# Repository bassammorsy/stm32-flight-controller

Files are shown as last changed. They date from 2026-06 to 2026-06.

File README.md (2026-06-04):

# STM32F405 Quadcopter Flight Controller
A custom 4-layer flight controller PCB designed from scratch in KiCad, targeting Betaflight compatibility with 4S–6S LiPo input. Designed, laid out, and submitted for SMT assembly through JLCPCB.

## Specifications
| Parameter | Detail |
|---|---|
| Microcontroller | STM32F405RGTx — ARM Cortex-M4 @ 168 MHz |
| Input Voltage | 4S–6S LiPo (14.8V–25.2V) |
| Power Architecture | TPS54360DDA Buck (5V/3.5A) → SPX3819 LDO (3.3V) |
| IMU | ICM-42688-P (SPI1, 6-DOF, 32kHz ODR) |
| Barometer | BMP388 (SPI3) |
| Magnetometer | QMC5883L (I2C2) |
| GPS | SAM-M10Q-00B (UART3, integrated antenna) |
| OSD | AT7456E with 27MHz crystal |
| USB | USB-C with USBLC6-2SC6 ESD protection |
| PCB | 4-Layer, 74×108mm, FR4 TG135, LeadFree HASL |
| Motor Outputs | 4× DShot (TIM1 CH1-3, TIM8 CH4) |
| Assembly | JLCPCB SMT — 43 component BOM |

## PCB Layout
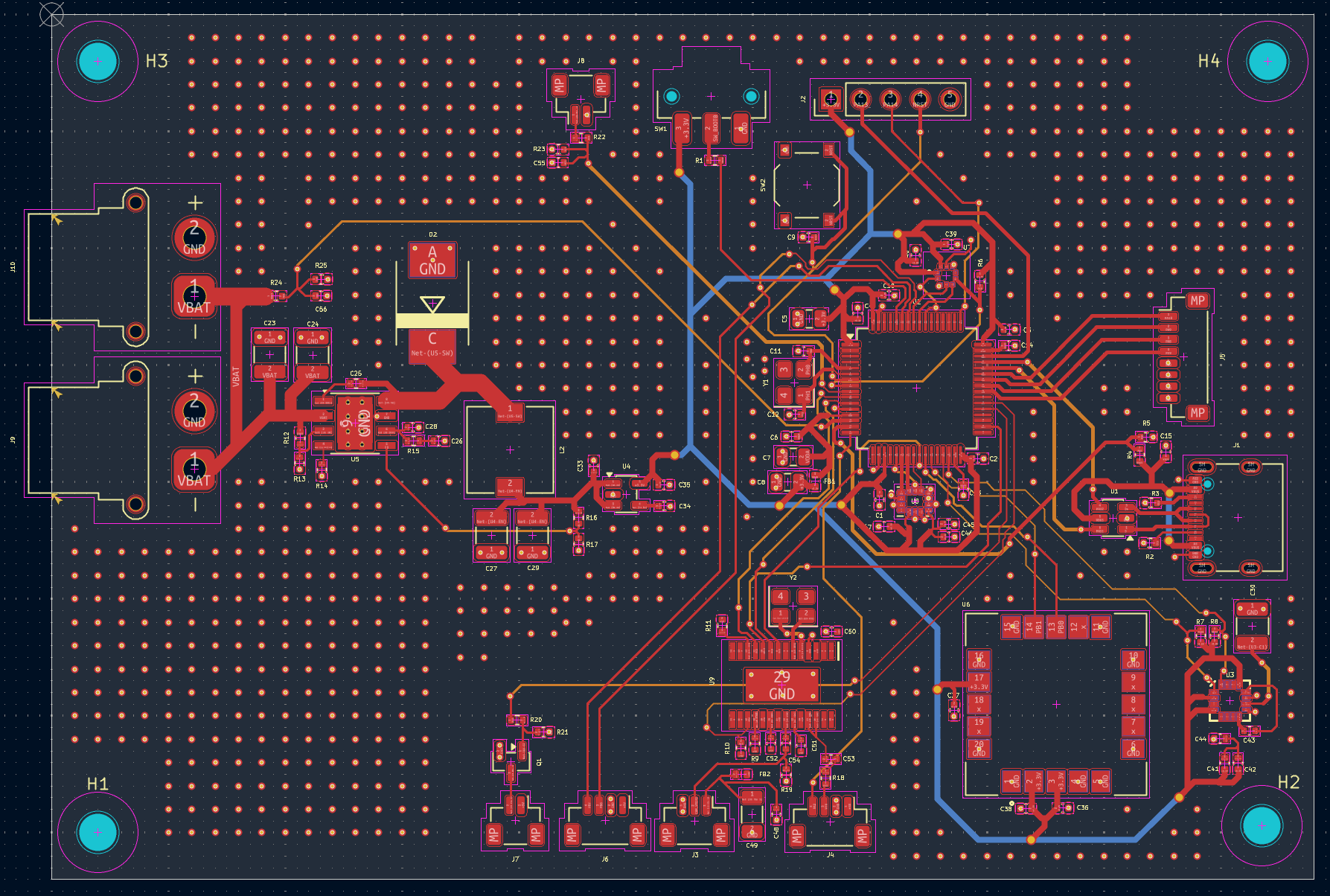
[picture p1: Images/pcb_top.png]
PCB Top View


## Design Portfolio
A full design portfolio documenting every schematic section, PCB layout decision, component selection rationale, and datasheet calculations is available below.

[📄 View Full Design Portfolio (PDF)](Docs/STM32_Drone_FC_Portfolio.pdf)

## Key Design Decisions
- 4-layer stackup: F.Cu (signals) / In1.Cu (GND plane) / In2.Cu (signal overflow) / B.Cu (3.3V distribution)
- Switched node area minimized around TPS54360 to reduce EMI
- Decoupling capacitors placed within 1–2mm of every power pin
- Ground via stitching at all signal layer transitions
- Magnetometer placed at maximum distance from power section
- USBLC6-2SC6 placed immediately at USB-C connector before any D+/D− routing

## Repository Structure

    Hardware/
        Schematic/     — KiCad schematic files
        PCB/           — KiCad PCB layout files
        Gerbers/       — Fabrication files for JLCPCB
    BOM/               — Bill of materials with LCSC part numbers
    Docs/              — Full design portfolio PDF

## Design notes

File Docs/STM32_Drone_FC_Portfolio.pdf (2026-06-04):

Custom STM32F405 Quadcopter Flight Controller — Design Portfolio

# STM32F405 QUADCOPTER FLIGHT CONTROLLER

## PCB Design Portfolio

Bassam Morsy | University of Washington
4-Layer KiCad Design | JLCPCB Fabrication | Betaflight Compatible
Microcontroller | STM32F405RGTx — ARM Cortex-M4 @ 168 MHz
Input Voltage | 4S–6S LiPo (14.8V–25.2V)
Power Architecture | TPS54360DDA Buck → 5V | SPX3819 LDO → 3.3V
IMU | ICM-42688-P (SPI1, 6-DOF, 32kHz ODR)
Sensors | BMP388 Baro | QMC5883L Mag | SAM-M10Q GPS
OSD | AT7456E with 27 MHz crystal
PCB | 4-Layer, 74×108 mm, HASL, FR4 TG135
Motor Outputs | 4× DShot (TIM1 CH1-3, TIM8 CH4)

STM32F405 Quadcopter FC — Design Portfolio | Page 2

Table of Contents 1 Project Overview 2 System Architecture 3 Power Architecture

### 3.1 TPS54360DDA Buck Converter 3.2 SPX3819M5-L-3-3 LDO Regulator 3.3 VDDA Analog Power Filter

### 4 STM32F405 Microcontroller

### 4.1 Power Decoupling Network 4.2 Crystal Oscillator (8 MHz) 4.3 BOOT0 Configuration 4.4 NRST Reset Circuit 4.5 SWD Debug Interface

5 USB-C Interface 6 Inertial Measurement Unit — ICM-42688-P 7 Barometer — BMP388 8 OSD — AT7456E 9 Magnetometer — QMC5883L

### 10 GPS — SAM-M10Q-00B 11 FPV Camera Input 12 Buzzer Driver 13 Connectors & Peripheral I/O 14 PCB Layout

14.1 Stackup & Layer Strategy 14.2 Overall Placement Strategy 14.3 Power Section Layout 14.4 STM32 Area Layout 14.5 IMU Layout 14.6 OSD & 5V Area Layout 14.7 Barometer Layout 14.8 Magnetometer Layout 14.9 GPS Module Layout 14.10 USB-C Layout 14.11 Crystal & VDDA Layout 14.12 Trace Widths & Impedance 14.13 Ground Plane Strategy

### 15 Manufacturing & BOM

# 1. Project Overview

This portfolio documents the complete design of a custom quadcopter flight controller built from scratch using KiCad EDA. The board targets Betaflight firmware compatibility and is designed for 4S–6S LiPo battery systems (14.8V–25.2V nominal). Every component value, footprint, and routing decision was made with explicit engineering justification grounded in datasheets, signal integrity principles, and power electronics theory. The board was fabricated by JLCPCB as a 4-layer PCB and partially assembled via their SMT service, with through-hole and large SMD connectors hand-soldered.

The design goal was to produce a professional-grade flight controller equivalent to commercial offerings such as the Matek F405 or Holybro Kakute F4, while applying first-principles engineering at every stage. This includes full datasheet-driven component selection, calculated feedback networks, analog power isolation, differential pair routing, and a deliberate 4-layer stackup strategy to minimize EMI and maximize signal integrity.

# 2. System Architecture

The flight controller is organized around three functional domains: power conversion, the main processing core, and the sensor/peripheral subsystem. Battery voltage enters through two XT30 connectors (J9 for ESC power pass-through, J10 for FC input), is stepped down by a synchronous buck converter to 5V, then regulated further by an LDO to 3.3V for digital logic and sensors. The analog supply (VDDA) for the STM32's ADC is further filtered from the 3.3V digital rail using a ferrite bead and capacitor network.

Block | Component | Interface | Rail
Main MCU | STM32F405RGTx | — | 3.3V
Buck Converter | TPS54360DDA | — | VBAT → 5V
LDO | SPX3819M5-L-3-3 | — | 5V → 3.3V
IMU | ICM-42688-P | SPI1 (PA5/6/7, CS:PC4) | 3.3V
Barometer | BMP388 | SPI3 (PB3/4/5, CS:PC0) | 3.3V
Magnetometer | QMC5883L | I2C2 (PB10/11) | 3.3V
GPS | SAM-M10Q-00B | UART3 (PB0/1) | 3.3V
OSD | AT7456E | SPI2 (PC3/PB13/PC2, CS:PC5) | 5V
ESD Protection | USBLC6-2SC6 | USB D+/D− | —
Motor Outputs | 4× JST-SH | TIM1 CH1-3, TIM8 CH4 | 5V
Receiver | JST-SH 4-pin (J5) | UART1 (PA9/10) | 5V
VTX | JST-SH 4-pin (J4) | UART2 (PA2) | 5V

# 3. Power Architecture

The power system must handle a wide input range (4S LiPo: 14.8V nominal, 16.8V full charge; 6S: 22.2V nominal, 25.2V full charge) and deliver clean, stable power to a mixed analog-digital load. A two-stage approach was chosen: a high-efficiency switching buck converter to handle the large voltage step-down, followed by a low-noise LDO for the final digital rail, with additional LC filtering for the sensitive analog domain.

## 3.1 TPS54360DDA Buck Converter — VBAT → 5V @ 3.5A

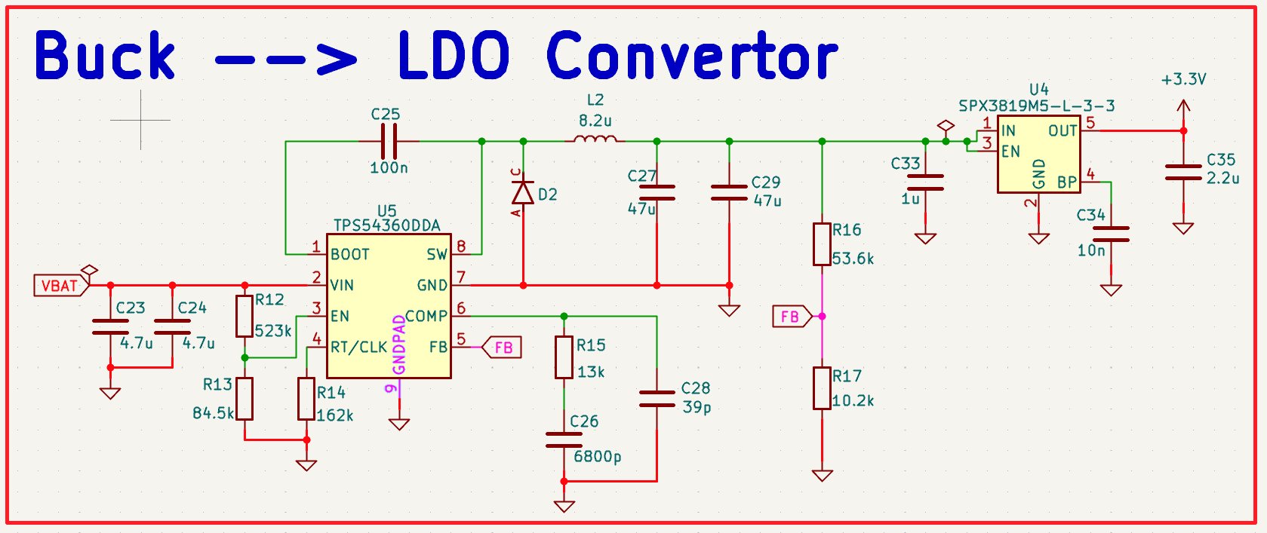
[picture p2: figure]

Figure 1: Complete power section schematic — TPS54360DDA buck converter and SPX3819 LDO

The Texas Instruments TPS54360DDA was selected for its wide input voltage range (4.5V–60V), 3.5A continuous output capability, internal high-side MOSFET, and availability through JLCPCB assembly. The switching frequency was set to 600 kHz by the RT resistor R14 (162 kΩ), calculated directly from the TPS54360 datasheet equation: R_T = (1/f_sw − 100ns) / (10.05 × 10■¹²). Higher switching frequency allows a smaller inductor at the cost of slightly higher switching losses — 600 kHz is the recommended sweet spot for this IC balancing efficiency and component size.

Output Voltage Feedback Network (R15, R16, R17):
R15 (upper, FB to VOUT) = 13 kΩ
R16 (lower, FB to GND) — sets output voltage via voltage divider
Target output: 5.0V. Equation: V_OUT = V_REF × (1 + R_upper/R_lower), V_REF = 0.8V Calculated: R16 = 10.2 kΩ, R17 = 53.6 kΩ — verified against datasheet
UVLO (Undervoltage Lockout) — R12, R13:
R12 = 523 kΩ (upper), R13 = 84.5 kΩ (lower)
Sets UVLO start threshold ~14.5V and stop ~13V, preventing operation below 4S minimum Protects battery from deep discharge and ensures stable startup
Compensation Network — R15, C26, C28:
R15 = 13 kΩ, C26 = 6800 pF, C28 = 39 pF
Type II compensation network stabilizes the control loop across all load conditions
C26 sets the zero frequency, C28 adds a high-frequency pole to attenuate switching noise

Values calculated per TPS54360 datasheet Section 9.2 compensation procedure Inductor — L2 (8.2 µH):
L = (V_IN − V_OUT) / (f_sw × ∆I_L) — calculated for 30% peak-to-peak current ripple At V_IN=25.2V, V_OUT=5V, f_sw=600kHz, I_OUT=3A: L ≈ 8.2 µH
RS0630-8R2MS selected: 7.3×7.3mm power inductor, I_sat > 4A, low DCR
Catch Diode — D2 (B560C-13-F):
Schottky diode, 60V/5A rated, DO-214AB (SMA-C) package
Placed as close as possible to the SW pin — this is the critical hot node
Low forward voltage (0.52V typ) minimizes conduction losses during freewheeling phase Input Capacitors — C23, C24 (4.7 µF × 2, 1210):
Placed immediately at VBAT/VIN pins to decouple high-frequency switching transients 1210 package chosen for high voltage rating (≥50V) and low ESR at switching frequency Two caps in parallel halves effective ESL and ESR
Output Capacitors — C27, C29 (47 µF × 2, 1210):
Large bulk capacitance on output to minimize ripple and support load transients
Placed at output node, away from IC side, to complete the output current loop locally Bootstrap Cap — C25 (100 nF):
Connected between BOOT and SW pins per datasheet
Provides gate drive voltage for the internal high-side MOSFET
Must be placed as close to BOOT pin as possible

## 3.2 SPX3819M5-L-3-3 LDO — 5V → 3.3V

The MaxLinear SPX3819M5-L-3-3 LDO was chosen for its low dropout voltage (340 mV at 500 mA), low quiescent current (90 µA), and built-in enable pin and thermal/overcurrent protection. It takes the clean 5V buck output and produces 3.3V for the STM32 and all digital sensors. The total 3.3V load was calculated from datasheets: STM32F405 (~50 mA active), ICM-42688-P (3.1 mA), BMP388 (0.7 mA), QMC5883L (2.5 mA), SAM-M10Q (15 mA typ), plus decoupling overhead, totaling approximately 99 mA — well within the 500 mA rating.

Input cap C33 = 1 µF (stability, placed at IN pin)
Output caps C34 (10 nF) + C35 (2.2 µF) — output filter, improves PSRR and transient response
EN pin connected via R16/R17 voltage divider from buck output — enables LDO only when 5V is stable BP pin bypassed with 10 nF (C34) per datasheet requirement

## 3.3 VDDA Analog Power Filter

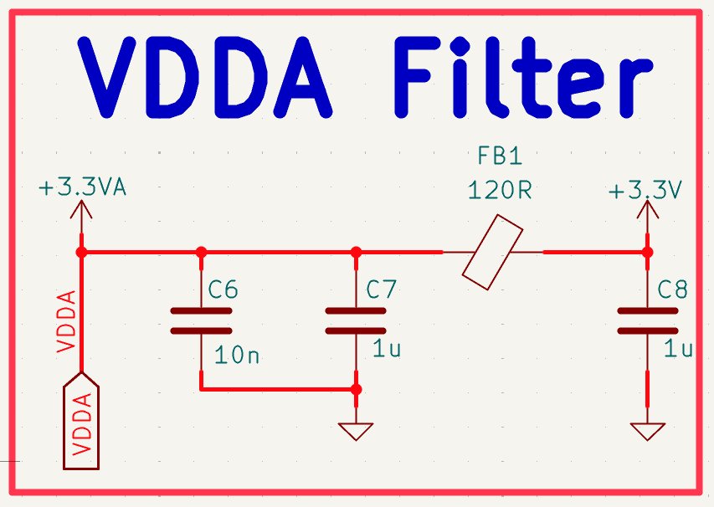
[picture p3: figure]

Figure 2: VDDA analog supply filter — FB1 ferrite bead with C6/C7/C8 capacitor network

The STM32F405 has a dedicated VDDA pin for its ADC, DAC, and analog comparator circuitry. Feeding VDDA directly from the digital 3.3V rail would couple switching noise and digital ground bounce directly into the ADC reference, degrading measurement accuracy. A ferrite bead filter was therefore implemented between the digital 3.3V rail and VDDA.

FB1 — 120 Ω @ 100 MHz, 0402:
Sunlord GZ1005D121TF ferrite bead acts as a low-pass filter at high frequencies
Passes DC and low-frequency signals (negligible DC resistance) but attenuates switching noise above ~10 MHz 120 Ω impedance at 100 MHz chosen per STM32F4 reference manual recommendation
Filter Capacitors:
C6 = 10 nF (0402): high-frequency bypass, targets self-resonance near 100 MHz
C7 = 1 µF (0805): mid-frequency bulk decoupling, handles lower-frequency noise
C8 = 1 µF (0805): post-ferrite output stabilization on VDDA side
The combination creates a cascaded LC filter providing >40 dB attenuation of switching noise above 10 MHz

# 4. STM32F405 Microcontroller

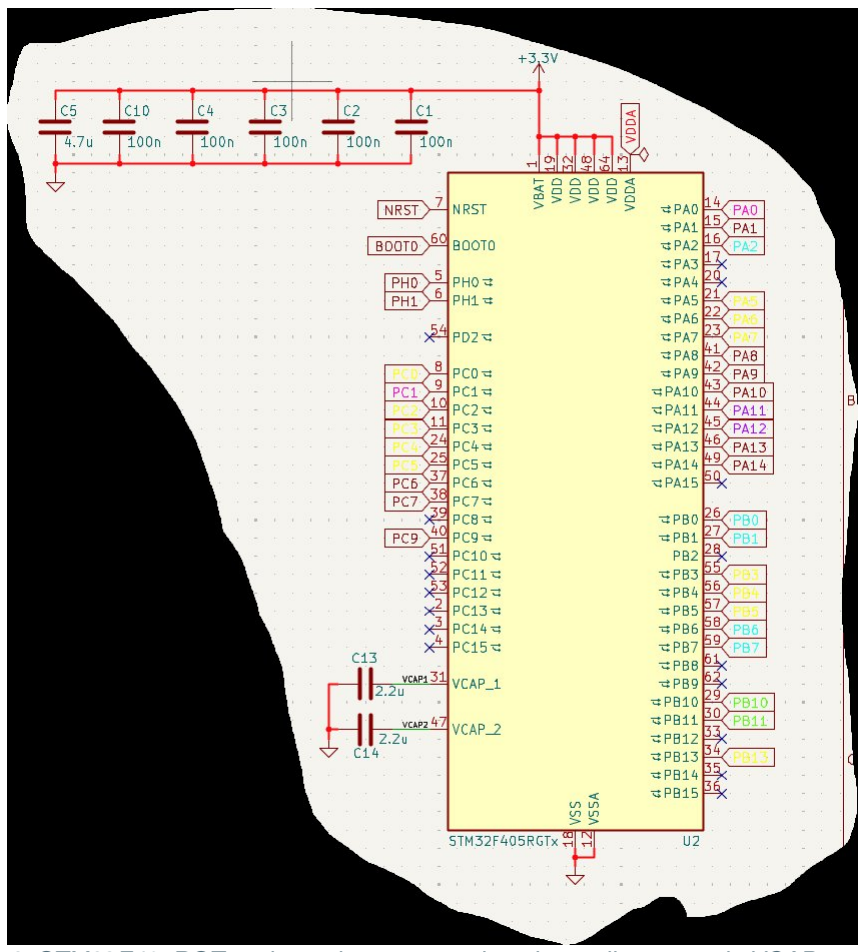
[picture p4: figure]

Figure 3: STM32F405RGTx schematic — power pins, decoupling network, VCAP capacitors

The STM32F405RGTx is an ARM Cortex-M4F microcontroller running at up to 168 MHz with an FPU. It was chosen over the STM32F411 specifically to gain additional UART peripherals, CAN bus support, and full alignment with existing Betaflight hardware targets. The LQFP-64 package was used for its 0.5 mm pitch solderable leads, allowing JLCPCB SMT assembly.

## 4.1 Power Decoupling Network

Per the STM32F405 datasheet Figure 17, each VDD pin must have its own 100 nF decoupling capacitor placed as close as possible to the pin. The STM32F405 has four VDD pins (pins 19, 48, 63, 64) and one VDDA pin. The decoupling strategy follows three principles:

C1–C4 = 100 nF 0402 (X7R) — one per VDD pin, placed within 1–2 mm of each pin
C5 = 4.7 µF 0805 — bulk bypass for the combined VDD network, handles low-frequency transients
VDDA supplied through FB1 ferrite filter (see Section 3.3)
The 100 nF capacitors are sized to have their self-resonant frequency near the switching frequencies of concern (~100 MHz for digital noise). At resonance, impedance is minimized to ESR only (~10 mΩ), providing the lowest possible impedance path for transient return current. Using 0402 packages minimizes parasitic inductance compared to larger packages, keeping self-resonant frequency high. The 4.7 µF bulk cap provides charge reservoir for larger, slower transients such as peripherals switching on.

VCAP Pins (C13, C14 = 2.2 µF each):
VCAP1 (pin 31) and VCAP2 (pin 47) connect to the internal voltage regulator output
The STM32F405 has an internal 1.2V core voltage regulator requiring external capacitors on VCAP for stability 2.2 µF specified by STM32F405 datasheet — must not be omitted or the core regulator will oscillate Connected to GND, not 3.3V — these are regulator output caps, not bypass caps

## 4.2 Crystal Oscillator — 8 MHz

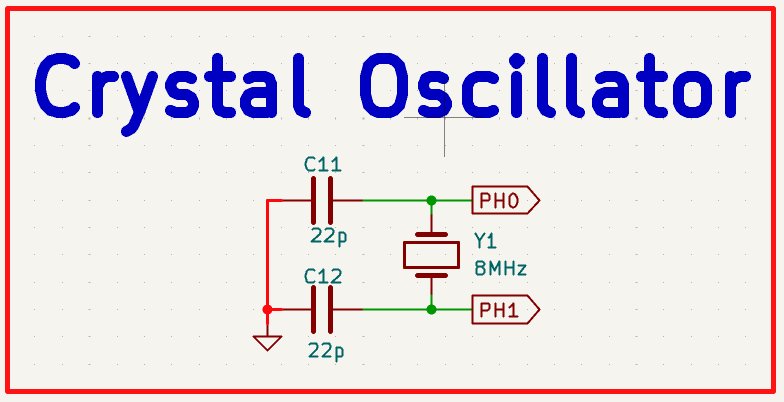
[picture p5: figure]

Figure 4: 8 MHz crystal oscillator circuit — Y1 with 22 pF load capacitors C11/C12

The STM32F405 uses a 4–26 MHz external crystal on the HSE (High Speed External) oscillator input at pins PH0 and PH1. An 8 MHz crystal was chosen because Betaflight targets the STM32F405 with an 8 MHz HSE, and the PLL is configured to multiply this to 168 MHz system clock. The crystal frequency must match the Betaflight firmware target configuration.

Load Capacitors — C11, C12 = 22 pF (C0G/NP0, 0402):
Crystal oscillator circuits require load capacitors on each pin to ground
Load capacitance C_L = (C11 × C12)/(C11 + C12) + C_stray ≈ 11 pF + C_stray
Typical stray capacitance ~3–5 pF, giving effective C_L ≈ 14–16 pF
C0G/NP0 dielectric chosen for temperature stability — critical for clock accuracy
Traces from crystal pins to STM32 kept as short as possible (<5 mm) to minimize stray capacitance
Traces surrounded by ground copper to shield from noise coupling
The 27 MHz crystal Y2 used for the AT7456E OSD follows the same design approach, as the OSD chip requires a separate clock independent of the MCU.

## 4.3 BOOT0 Configuration

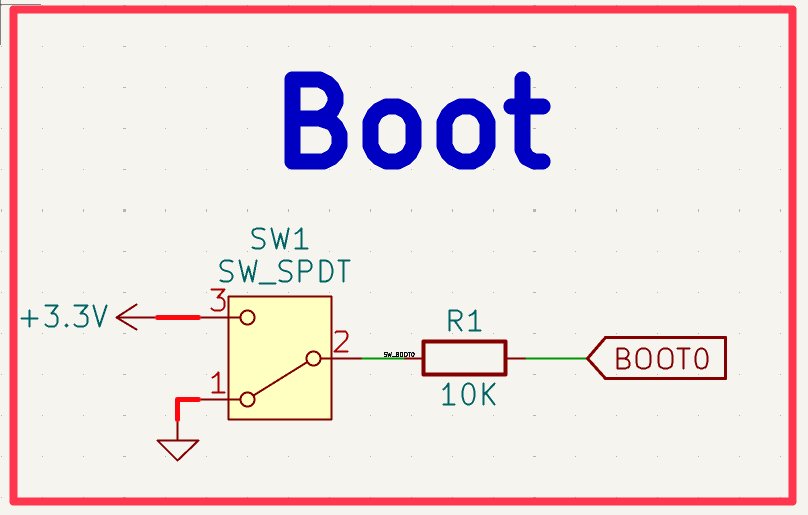
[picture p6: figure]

Figure 5: BOOT0 circuit — SPDT slide switch SW1 with 10 kΩ pull-down R1

The BOOT0 pin determines the boot mode of the STM32 on reset. When BOOT0 is low (GND), the STM32 boots from user flash — normal operation for Betaflight. When BOOT0 is pulled high (3.3V), the STM32 enters the internal bootloader, enabling USB DFU firmware flashing without a separate programmer.

SW1 = C&K; JS102011SAQN SPDT slide switch — selects between GND and 3.3V
R1 = 10 kΩ pull-down — ensures BOOT0 defaults to GND when switch is in run position
10 kΩ chosen to limit current while providing a strong enough logic low against noise
This eliminates the need for an ST-LINK for routine firmware updates — the user simply slides SW1, plugs in USB, and flashes via DFU, then slides back for normal operation.

## 4.4 NRST Reset Circuit

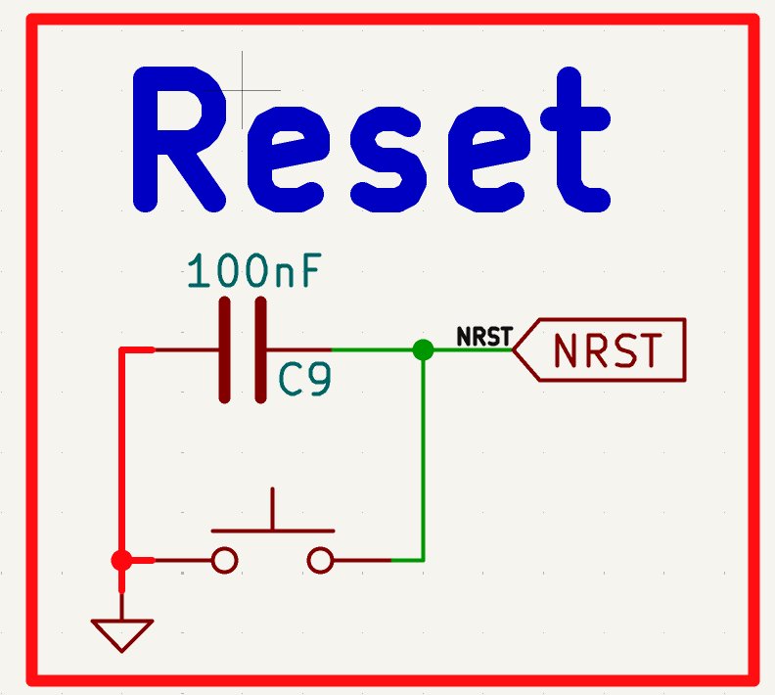
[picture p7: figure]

Figure 6: NRST reset circuit — momentary push button with 100 nF filter capacitor C9

The NRST pin is an active-low reset. A momentary push button (SW2) pulls NRST to GND when pressed, resetting the MCU. C9 (100 nF) is placed between NRST and GND as specified in the STM32 reference manual to filter out noise and ESD spikes on the reset line, preventing spurious resets in the electrically noisy drone environment.

STM32 internal pull-up keeps NRST high during normal operation
C9 = 100 nF creates an RC filter — time constant with internal ~40 kΩ pull-up is ~4 ms
This debounces the mechanical switch and filters conducted EMI from ESCs

## 4.5 SWD Debug Interface

Figure 7: 5-pin SWD debug header J2 — SWDIO/PA13, SWCLK/PA14, NRST, 3.3V, GND

A 5-pin 2.54mm pitch through-hole header provides Serial Wire Debug (SWD) access. SWD requires only SWDIO (PA13) and SWCLK (PA14) plus ground for full debug capability, including breakpoints, register inspection, and memory access via an ST-LINK V2 probe. NRST and 3.3V are included for convenience — NRST allows the debugger to reset the target, and 3.3V allows the probe to power the board from the debug connector during development.

PA13 = SWDIO — bidirectional data, 2.2 kΩ internal pull-up on STM32
PA14 = SWCLK — clock from debug host, 40 kΩ internal pull-down on STM32
Pinout matches standard ARM 5-pin SWD layout for ST-LINK compatibility

# 5. USB-C Interface

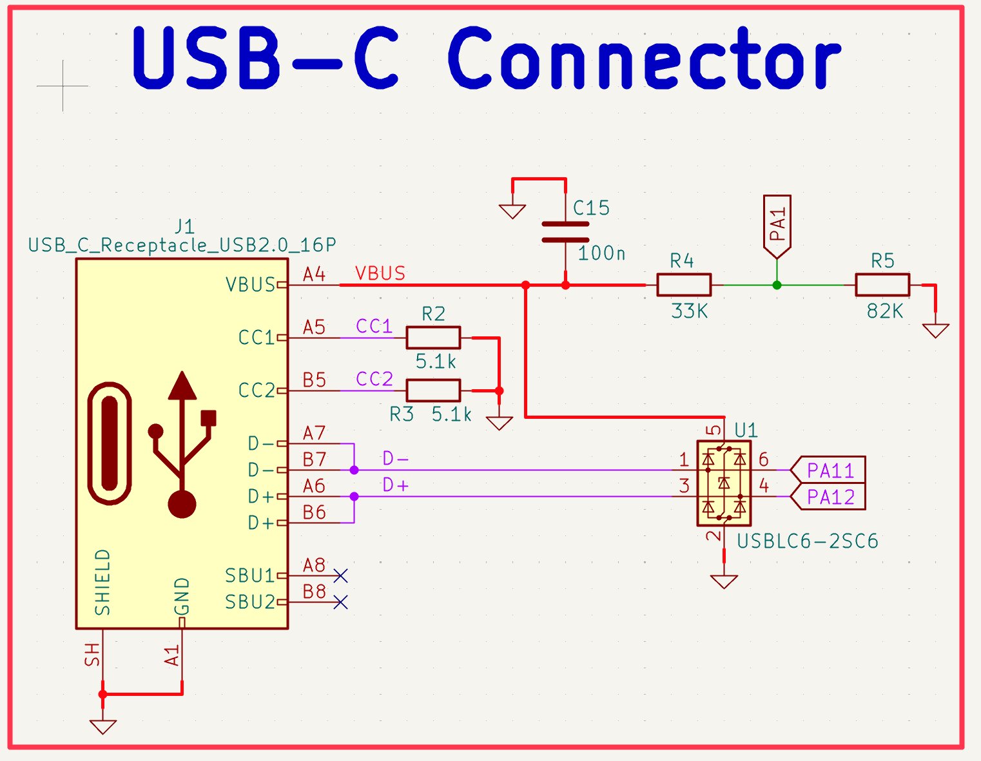
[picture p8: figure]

Figure 8: USB-C schematic — J1 connector, ESD protection U1, CC pull-downs, VBUS sense

USB-C is used for firmware flashing via DFU and Betaflight Configurator communication. The STM32F405 has a built-in USB OTG FS peripheral connected to PA11 (D−) and PA12 (D+). The design implements USB 2.0 Full Speed (12 Mbps) — sufficient for all configurator functions.

ESD Protection — U1 (USBLC6-2SC6, SOT-23-6):
ST USBLC6-2SC6 is specifically designed for USB 2.0 line protection
Ultra-low capacitance: 3.5 pF max — critical to not degrade USB signal integrity
Higher capacitance TVS diodes would round the USB signal edges and cause bit errors Handles ±8 kV ESD strikes per IEC 61000-4-2 — protects STM32 USB pins from hot-plugging Placed as close as possible to the USB connector, before any signal routing
CC Pull-Down Resistors — R2, R3 (5.1 kΩ):
USB-C CC (Configuration Channel) pins determine the role of each connector
5.1 kΩ pull-downs on CC1 and CC2 advertise this device as a USB device (sink)
This is required for USB-C to USB-A cables to work — the host sees a valid device Without these resistors, USB-C hosts may not negotiate power or enumerate the device Value per USB-C specification Table 4-25: Rd = 5.1 kΩ for default USB device role VBUS Sense Divider — R4 (33 kΩ), R5 (82 kΩ):
VBUS (5V from USB host) is divided down to <3.3V for the STM32 PA1 ADC pin V_PA1 = 5V × 82k/(33k+82k) = 3.57V — slightly high, but PA1 is 5V tolerant on F405

Allows firmware to detect USB connection state and switch between USB and UART modes Design follows ST Application Note AN4879 for USB-C on STM32
C15 = 100 nF decouples VBUS at the sense point
D+/D− Routing:
USB 2.0 differential pair routed as matched-length traces
Both sides of the USB-C connector (A6/B6 for D+, A7/B7 for D−) tied together per USB-C spec SBU1 and SBU2 left as no-connect — not used for USB 2.0

# 6. Inertial Measurement Unit — ICM-42688-P

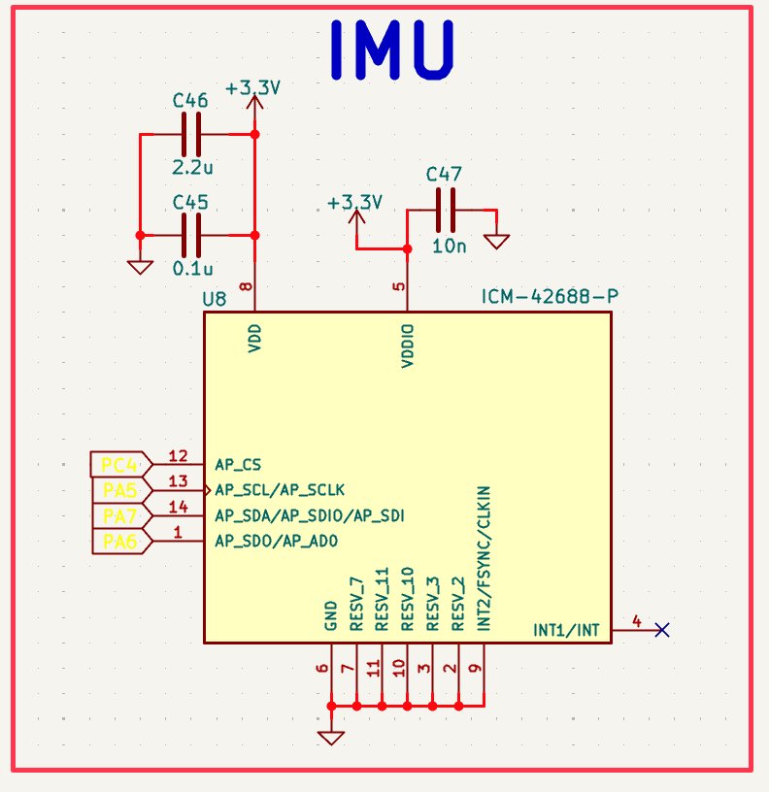
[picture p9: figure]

Figure 9: ICM-42688-P IMU schematic — SPI1 interface, VDD/VDDIO decoupling

The TDK InvenSense ICM-42688-P is a 6-axis IMU (3-axis gyroscope + 3-axis accelerometer) selected for its industry-leading noise density (gyro: 2.8 mdps/√Hz), 32 kHz ODR capability, and native SPI support up to 24 MHz. It is the current state-of-the-art IMU used in high-performance flight controllers, replacing the older MPU-6000/ICM-20689 series. Its performance directly determines flight controller loop quality.

Interface — SPI1 (PA5/PA6/PA7, CS: PC4):
PA5 = SPI1_SCK (SCLK) — clock up to 24 MHz in SPI mode 3
PA6 = SPI1_MISO (AP_SDO) — data from IMU to MCU
PA7 = SPI1_MOSI (AP_SDA/AP_SDIO) — data from MCU to IMU
PC4 = dedicated chip select (active low) — GPIO controlled by firmware
SPI chosen over I2C for speed: 24 MHz SPI vs 400 kHz I2C max
At 24 MHz SPI, a full 6-axis read (12 bytes) completes in ~5 µs — critical for 8 kHz PID loops Power Supply Decoupling:
VDD pin (pin 8): C46 = 2.2 µF + C45 = 0.1 µF in parallel
2.2 µF handles bulk charge storage; 0.1 µF targets high-frequency noise
VDDIO pin (pin 5): C47 = 10 nF — IO logic supply, separate decoupling per datasheet
Both caps placed as close as possible to respective pins (<1 mm)
Separate VDD and VDDIO decoupling prevents digital switching on IO pins from coupling into the sensitive analog measurement core

RESV Pins:
All RESV (reserved) pins connected to GND per ICM-42688-P datasheet requirement Floating reserved pins can cause undefined behavior or increased noise floor INT1/INT pin left as no-connect — firmware polls via SPI rather than using interrupt

# 7. Barometer — BMP388

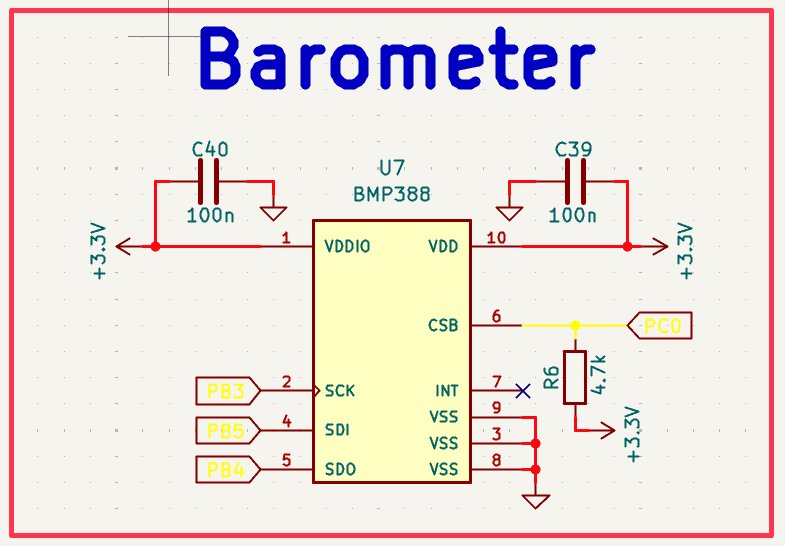
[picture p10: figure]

Figure 10: BMP388 barometer schematic — SPI3 interface, separate VDDIO/VDD decoupling

The Bosch BMP388 is a high-precision barometric pressure and temperature sensor used for altitude hold and variometer functions in Betaflight. It communicates via SPI3 and is powered from the 3.3V rail. The BMP388 was chosen over the older BMP280 for its improved noise performance (±0.08 hPa RMS) and lower current consumption.

Interface — SPI3 (PB3/PB4/PB5, CS: PC0):
PB3 = SPI3_SCK, PB4 = SPI3_MISO (SDO), PB5 = SPI3_MOSI (SDI)
PC0 = chip select, with R6 (4.7 kΩ) pull-up to 3.3V
Pull-up on CS ensures the barometer is deselected (CS high) during power-up, preventing spurious SPI transactions before firmware initializes the bus
CSB must be pulled high within the BMP388 to select SPI mode over I2C
Decoupling — C39 (VDD), C40 (VDDIO) = 100 nF each:
BMP388 has separate VDD (power) and VDDIO (IO logic) supply pins
Independent decoupling on each pin prevents logic switching on VDDIO from disturbing the pressure measurement reference on VDD
100 nF value per BMP388 datasheet recommendation
INT pin left as no-connect — Betaflight driver polls the barometer at a fixed rate
VSS pins (3, 8, 9) all connected to GND pour

# 8. OSD — AT7456E

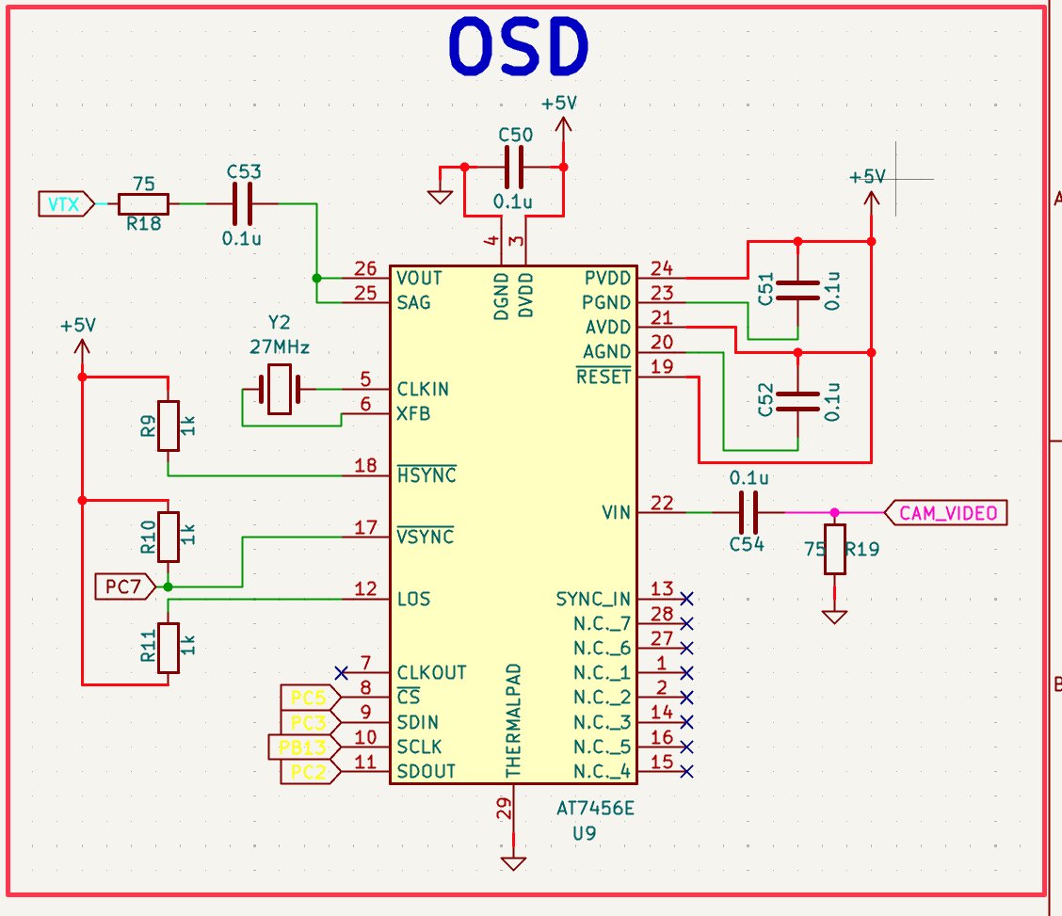
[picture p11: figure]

Figure 11: AT7456E OSD schematic — SPI2, 27 MHz crystal, video I/O with 75Ω termination

The ZHONGKEWEI AT7456E is an on-screen display (OSD) chip that overlays flight telemetry (speed, altitude, battery voltage, RSSI) onto the FPV camera video feed before transmission to the video transmitter. It operates on 5V (powered from the buck 5V rail) and communicates with the STM32 via SPI2.

Interface — SPI2 (PC3/PB13/PC2, CS: PC5):
PC3 = SPI2_MOSI (SDIN), PB13 = SPI2_SCK (SCLK), PC2 = SPI2_MISO (SDOUT)
PC5 = chip select, PC7 = LOS (Loss of Signal output from OSD)
PC7 monitors the OSD LOS pin — firmware can detect loss of camera sync
HSYNC (pin 18) and VSYNC (pin 17) connected to PC7 area for sync detection

### 27 MHz Crystal — Y2:

AT7456E requires an external 27 MHz crystal for its internal video clock PLL
27 MHz is the standard clock for PAL/NTSC video timing generation
Crystal connected to CLKIN (pin 5) and XFB (pin 6) — XFB is the crystal feedback pin R9, R10, R11 (1 kΩ each) form the bias network for the crystal oscillator amplifier Video Input — VIN (pin 22):
CAM_VIDEO net connects the FPV camera output to the OSD VIN pin
C54 = 0.1 µF AC coupling capacitor — removes DC bias from camera signal R19 = 75 Ω termination to GND — matches video impedance standard (75 Ω) Without 75 Ω termination, video signal reflections cause ghosting artifacts

Video Output — VOUT (pin 26):
R18 = 75 Ω series termination on VOUT to VTX connector C53 = 0.1 µF AC coupling on VTX signal
SAG pin (25) connected — monitors sync amplitude for AGC
Power Supply — PVDD, AVDD (5V):
C50, C51, C52 = 0.1 µF decoupling on PVDD, AVDD, and DGND/DVDD pins AT7456E requires separate decoupling on analog and digital supply domains RESET pin tied high (to 5V) through resistor network — chip active on power-up

# 9. Magnetometer — QMC5883L

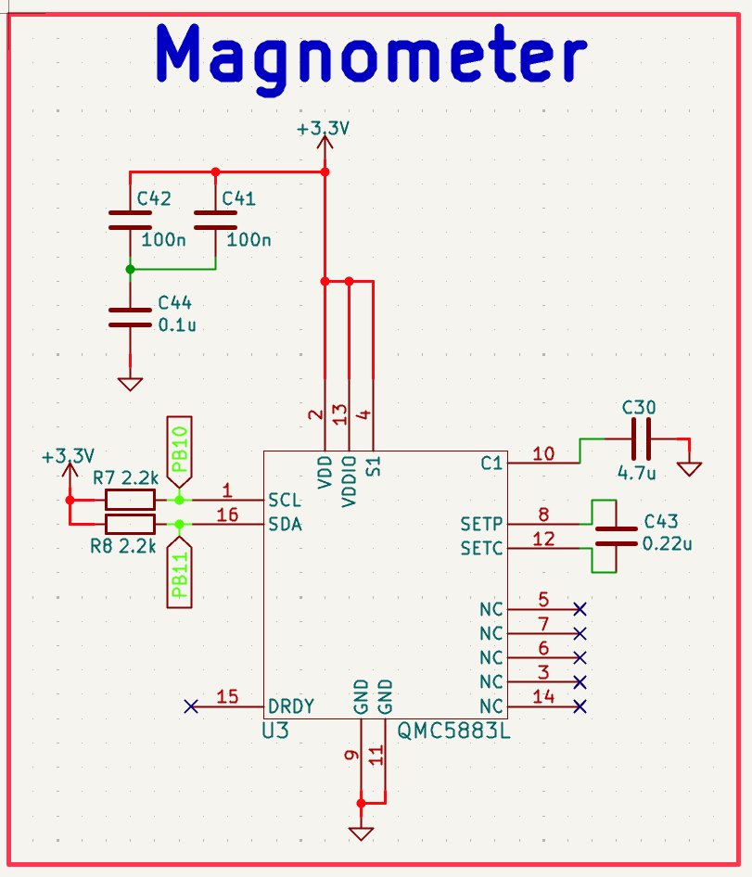
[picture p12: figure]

Figure 12: QMC5883L magnetometer schematic — I2C2 with pull-ups, SET/RESET capacitors

The QST QMC5883L is a 3-axis magnetic sensor providing heading information for GPS navigation and compass hold. It operates on I2C2 and uses an HMC5883L-compatible register set, allowing direct compatibility with existing Betaflight magnetometer drivers.

Interface — I2C2 (PB10/PB11):
PB10 = I2C2_SCL, PB11 = I2C2_SDA
R7 = R8 = 2.2 kΩ pull-up resistors to 3.3V on SCL and SDA
Pull-up value selection: I2C bus capacitance ~50 pF, f_SCL = 400 kHz (Fast mode) Time constant RC = 2.2 kΩ × 50 pF = 110 ns — safely below the 300 ns Fast mode limit Lower values (1 kΩ) would increase current draw; higher (4.7 kΩ) would slow edge rates SET/RESET Circuit — C43 (0.22 µF) between SETP/SETC:
The QMC5883L requires periodic SET/RESET pulses to demagnetize internal sense elements C43 = 0.22 µF connected between SETP (pin 8) and SETC (pin 12)
The IC drives a current pulse through C43 to generate the magnetic reset pulse
Value from QMC5883L application note — must not be omitted or compass calibration drifts Decoupling:
C41, C42 = 100 nF on VDD and VDDIO
C44 = 0.1 µF additional bypass on VDD
C30 = 4.7 µF bulk cap on C1 pin (internal charge pump output)

S1 pin connected to VDD per datasheet — enables I2C mode
Placement Consideration:
The QMC5883L measures Earth's magnetic field, which is very weak (~25–65 µT). Any nearby current-carrying traces create magnetic fields that dwarf the Earth's field, corrupting compass readings. For this reason the magnetometer should be mounted as far as possible from high-current paths — ideally on a mast or at the board edge away from motor power traces, ESC wiring, and the power section. In this design it is placed at the far corner of the board from the power section, and in a production implementation would typically be on an external module connected via the I2C header.

# 10. GPS — SAM-M10Q-00B

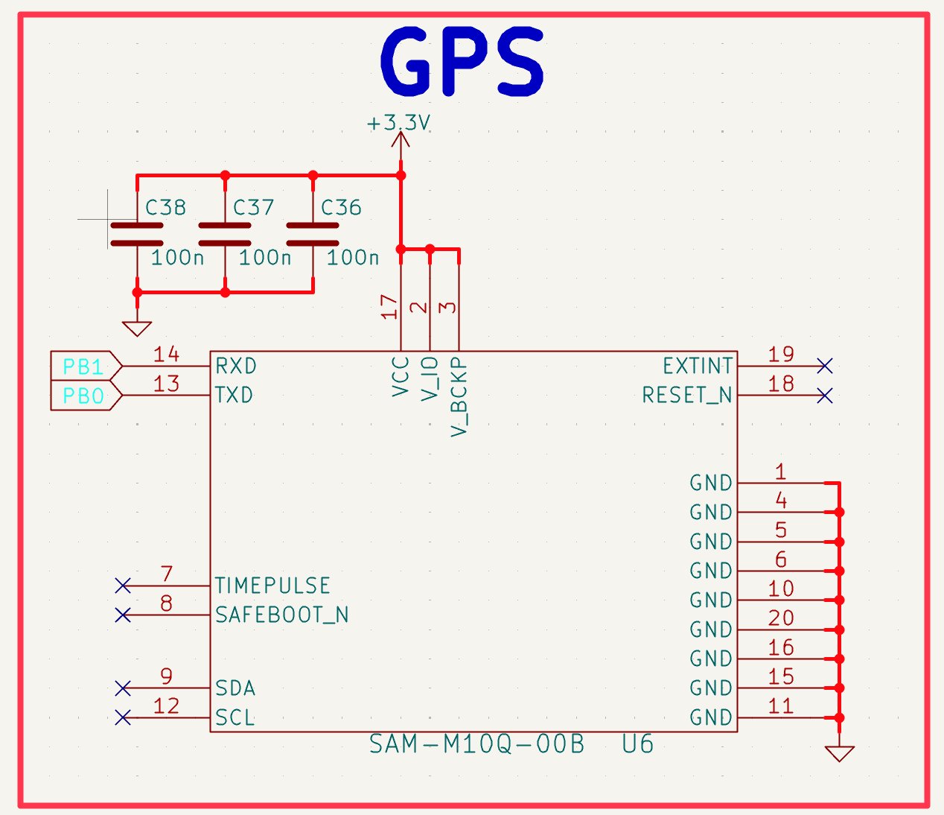
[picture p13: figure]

Figure 13: SAM-M10Q GPS module schematic — UART3, three-rail decoupling

The u-blox SAM-M10Q is a high-performance GNSS module in a compact 3×3 mm LCC package with an integrated patch antenna. It supports GPS, GLONASS, Galileo, and BeiDou simultaneously, providing position accuracy of ~1.5 m CEP. The module is mounted directly on the PCB rather than using an external GPS connected via JST cable, reducing wire inductance and weight.

Interface — UART3 (PB0/PB1):
PB0 = USART3_TX → GPS RXD (pin 14)
PB1 = USART3_RX → GPS TXD (pin 13)
Default baud rate: 9600 bps, upgradeable to 115200 via UBX configuration messages Simple UART — no hardware flow control required for GPS data rates
Power Supply — Three Independent Rails:
VCC (pin 17) = 3.3V: main module supply — C36 = 100 nF decoupling
V_IO (pin 2) = 3.3V: IO logic supply — C37 = 100 nF decoupling
V_BCKP (pin 3) = 3.3V: backup supply for RAM/RTC — C38 = 100 nF decoupling
Each rail has independent decoupling to prevent cross-coupling between domains V_BCKP keeps the GPS hot-start data alive — significantly reduces TTFF on power cycle Unused Pins:
TIMEPULSE (pin 7) and SAFEBOOT_N (pin 8) — left as no-connect
RESET_N (pin 18) — no-connect: internal pull-up keeps module running

EXTINT (pin 19) — no-connect: wake-on-movement not required
SDA/SCL (pins 9/12) — no-connect: I2C interface not used, UART selected
All GND pins (1, 4, 5, 6, 10, 11, 15, 16, 20) tied to GND plane
Placement Consideration:
The SAM-M10Q has an integrated patch antenna optimized to receive from directly above. It must be placed with a clear sky view — away from board edges that might block satellite signals, and with no metal components taller than the module within the antenna's field of view. The module is placed in the bottom-right corner of the board in a relatively unobstructed area.

# 11. FPV Camera Input

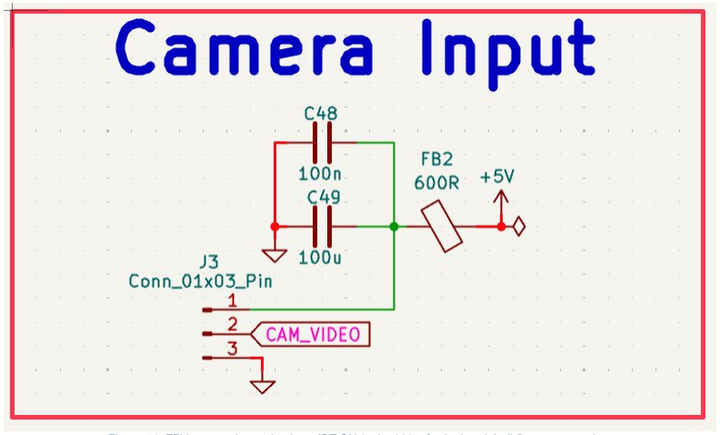
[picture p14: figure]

Figure 14: FPV camera input circuit — JST-SH 3-pin, 600Ω ferrite bead, bulk/bypass capacitors

The FPV camera input provides power and receives the analog video signal from the FPV camera. The 3-pin JST-SH connector (J3) carries +5V, video signal (CAM_VIDEO), and GND.

FB2 — 600 Ω @ 100 MHz Ferrite Bead:
The 5V camera power is filtered through a 600 Ω ferrite bead before the camera connector
FPV cameras contain switching regulators that generate conducted noise on the power rail The ferrite bead prevents camera switching noise from propagating back into the 5V bus 600 Ω chosen for higher attenuation than the 120 Ω FB1 — camera noise is typically stronger C49 — 100 µF 1206:
Large bulk capacitor on the camera power line after the ferrite bead
Acts as local charge reservoir — cameras draw sudden current spikes when driving video Prevents voltage droop on the camera supply during high-current transients
1206 package for adequate voltage rating and low ESR
C48 — 100 nF:
High-frequency bypass in parallel with C49 — handles fast transients C49 is too slow for Placed as close as possible to the connector power pin
CAM_VIDEO Net:
Video signal pin (pin 2) connects to CAM_VIDEO global net label
This net routes to the OSD VIN pin (AT7456E) via AC coupling capacitor C54

# 12. Buzzer Driver

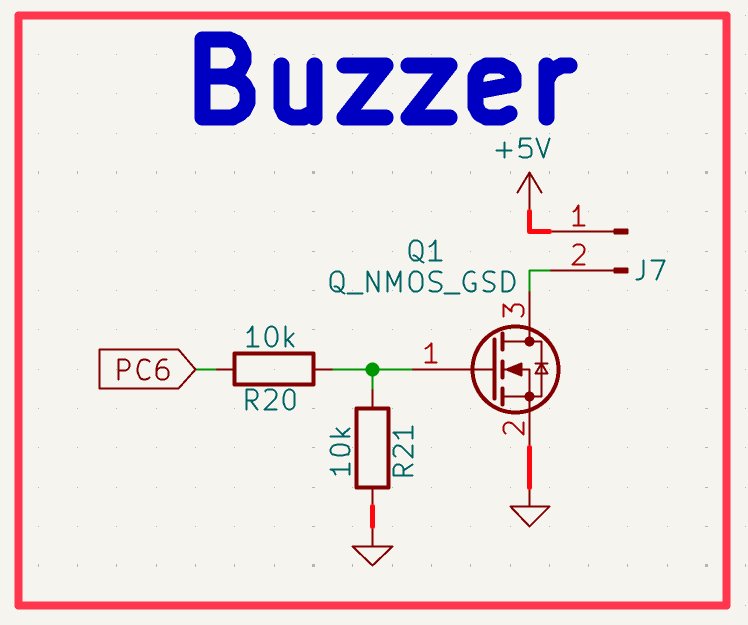
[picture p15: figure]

Figure 15: Buzzer driver circuit — NMOS Q1 with gate resistor/pull-down, 5V buzzer connector J7

The buzzer provides audible alerts for arming, disarming, low battery, and lost model beeping. Since the STM32 GPIO can only source ~25 mA and a buzzer typically requires 100–200 mA at 5V, a MOSFET switch is used to drive the buzzer from the 5V rail.

Q1 — N-channel MOSFET (SOT-23):
STM32 PC6 GPIO drives the MOSFET gate through R20 (10 kΩ series resistor)
R20 limits gate current and slows gate charge to reduce EMI from fast switching
R21 (10 kΩ pull-down to GND) ensures gate is held low when PC6 is high-impedance
Without R21, floating gate could cause buzzer to activate spuriously during boot
When PC6 goes high: MOSFET turns on, connects buzzer GND to system GND, buzzer sounds Buzzer connected between J7 and +5V — MOSFET switches the low side (GND)
Low-side switching is preferred: MOSFET source connected to GND, V_GS = V_PC6 = 3.3V No bootstrap circuit needed — straightforward enhancement-mode NMOS operation

# 13. Connectors & Peripheral I/O

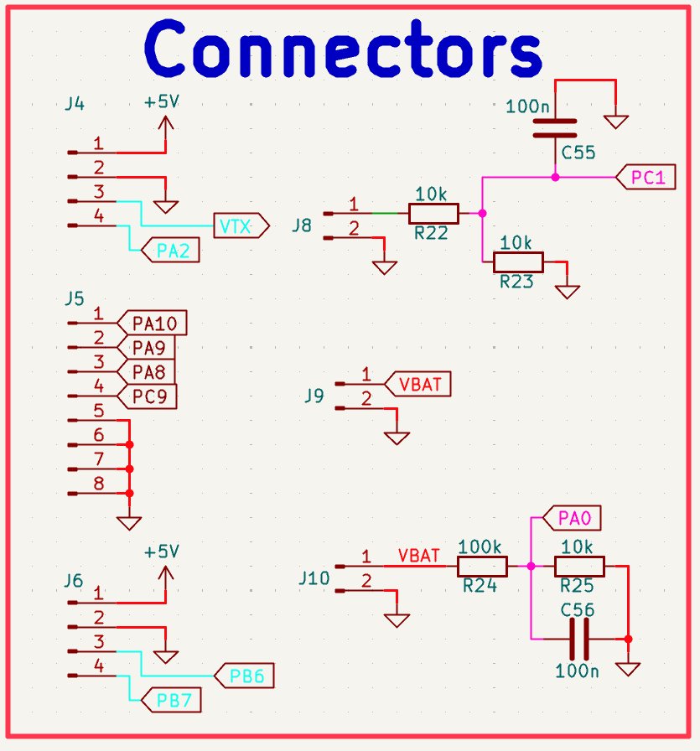
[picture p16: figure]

Figure 16: Peripheral connectors — motor ESC outputs (J4/J5/J6/J7), VTX, receiver, battery sense

All peripheral connectors use JST-SH 1.0 mm pitch (BM-series) for signal connections and XT30 for power. JST-SH was chosen for its small size (critical on a compact FC), positive retention locking, and industry standard use in FPV hardware.

Motor ESC Outputs — J5 (8-pin JST-SH):
PA10 (TIM1_CH3), PA9 (TIM1_CH2), PA8 (TIM1_CH1) = Motor 1/2/3 DShot outputs
PC9 (TIM8_CH4) = Motor 4 DShot output
Remaining pins = GND and +5V for ESC signal reference and BEC
DShot is a digital motor protocol — eliminates analog PWM calibration, provides error checking, and supports bidirectional telemetry
Receiver Input — J5 (4-pin JST-SH, separate):
PA10/PA9 = USART1 RX/TX for CRSF/ELRS ExpressLRS receiver protocol
+5V and GND for receiver power — most modern receivers run on 5V
VTX — J4 (4-pin JST-SH):
PA2 = USART2_TX for SmartAudio VTX control
+5V and GND for VTX power
SmartAudio allows Betaflight to control VTX power level, channel, and pit mode Current Sensor — J8 (2-pin):
PC1 = ADC input for current sensor analog output

R22/R23 (10 kΩ) voltage divider scales sensor output to ADC range C55 = 100 nF anti-aliasing filter on ADC input
Allows Betaflight to display real-time current draw and mAh consumed Battery Voltage Sense — J10/R24/R25:
J10 = XT30 battery connector (also main power input)
R24 = 100 kΩ (upper), R25 = 10 kΩ (lower) voltage divider
Scales VBAT (up to 25.2V) to PA0 ADC: V_PA0 = 25.2 × 10k/(100k+10k) = 2.29V — within 3.3V ADC range C56 = 100 nF anti-aliasing filter
Allows Betaflight to display cell voltage and trigger low battery warnings
ESC Power — J9 (XT30):
Passes VBAT directly to ESCs — no filtering (ESCs have their own capacitors) XT30 rated for 30A continuous — adequate for 4× brushless motors

# 14. PCB Layout

## 14.1 Stackup & Layer Strategy

The board uses a 4-layer JLCPCB standard stackup: F.Cu / In1.Cu / In2.Cu / B.Cu, with 1 oz copper on outer layers and 0.5 oz on inner layers (upgraded to 1 oz for this design). Total board thickness: 1.6 mm. Board dimensions: 74 × 108 mm.

Layer | Function | Contents
F.Cu (Top) | Signal + Component | Component pads, critical short traces, power traces from vias
In1.Cu | Ground Plane | Solid unbroken GND — reference plane for all signals
In2.Cu | Signal Overflow | Secondary signal routing when F.Cu is congested
B.Cu (Bottom) | 3.3V Distribution | 3.3V power backbone, bottom-side pads, ground pour

The key architectural decision was to use B.Cu as the 3.3V distribution backbone. 3.3V is distributed across the bottom copper layer as a wide pour, with vias popping up to F.Cu pads at each component. This keeps the top layer clean for signal routing and maintains a near-continuous ground plane on In1.Cu directly above all F.Cu signals. In2.Cu handles signal overflow — UART traces, SWD, and other low-priority signals that cannot be routed on F.Cu without excessive congestion.

The ground plane on In1.Cu is intentionally kept as a solid copper pour with no signal routes cutting through it. Any signal that must cross layers does so via a via, and a ground via is placed as close as possible to the signal via to provide a local return path. Without this, the return current must travel a longer path around the signal via, creating a loop antenna that radiates EMI.

## 14.2 Overall Placement Strategy

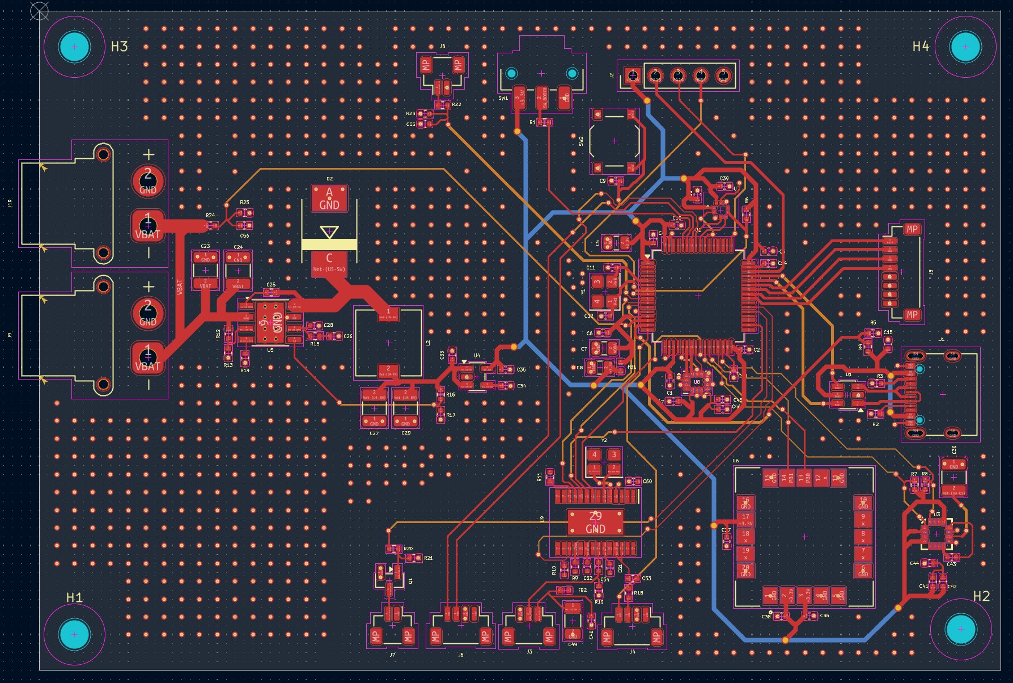
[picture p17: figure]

Figure 17: Full PCB top view — component placement overview

Component placement follows a functional grouping strategy, with high-power and noisy circuits physically separated from sensitive analog and high-frequency digital circuits. The power section (buck converter, inductor, diode, bulk capacitors) occupies the left side of the board, as far as possible from the IMU and barometer. The STM32 is centrally located with its decoupling caps immediately adjacent. The magnetometer is at the far bottom-right corner — maximum distance from all high-current paths. The GPS module is at the bottom-center, positioned for clear sky view. Motor output connectors are along the bottom edge for clean wiring to ESCs.

Four M3 mounting holes (H1–H4) at the corners are placed outside all routing areas and provide mechanical attachment to the drone frame. The 74×108 mm board size was chosen to match common 30.5×30.5 mm and 20×20 mm FC mounting patterns when centered.

## 14.3 Power Section Layout

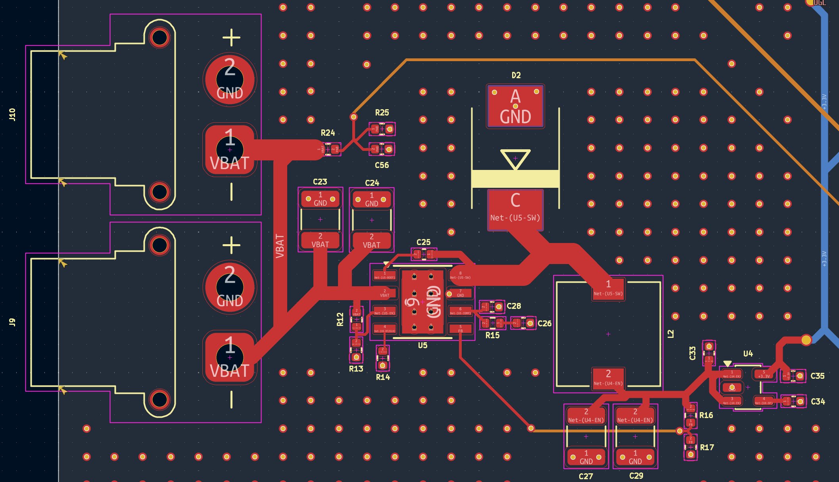
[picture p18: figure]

Figure 18: Power section PCB layout — TPS54360, inductor L2, diode D2, bulk capacitors

The power section layout is critical for EMI and efficiency. The TPS54360DDA (U5) is placed with the input capacitors (C23, C24) immediately to its left at the VIN pin, and the output capacitors (C27, C29) to its right after the inductor. This minimizes the area of both the input and output current loops.

Switched Node (SW — Net-(U5-SW)):
The SW node trace (between pin 8, D2, and L2) is kept as short and narrow as possible
No copper poured over or near the SW node — this trace switches at 600 kHz with 25V swings, radiating EMI proportional to its area
D2 catch diode placed as close to TPS54360 SW pin as physically possible
Ground return from D2 is a short, direct trace to the GNDPAD thermal via array
GNDPAD Thermal Vias:
The TPS54360DDA has an exposed thermal pad (pin 9) on the bottom of the IC
Array of thermal vias connect this pad to the In1.Cu ground plane for heat dissipation Without thermal vias, the pad temperature would rise above the 150°C rating under load Input Capacitors — C23, C24 (4.7 µF, 1210):
Placed immediately adjacent to VIN pin — shortest possible trace
Ground pins of caps connect directly to GND pour with via to In1.Cu
Minimizes input loop inductance, reducing voltage spike on VIN during switching Output Capacitors — C27, C29 (47 µF, 1210):
Placed at the output end of the inductor, between inductor output and LDO input Both caps share a GND via cluster to minimize loop impedance
LDO — U4 (SPX3819, SOT-23-5):
Placed immediately to the right of the output capacitors
C33 (input cap) at IN pin, C34+C35 (output caps) at OUT pin

Short traces throughout — LDO output drives the global 3.3V B.Cu distribution plane

## 14.4 STM32 Area Layout

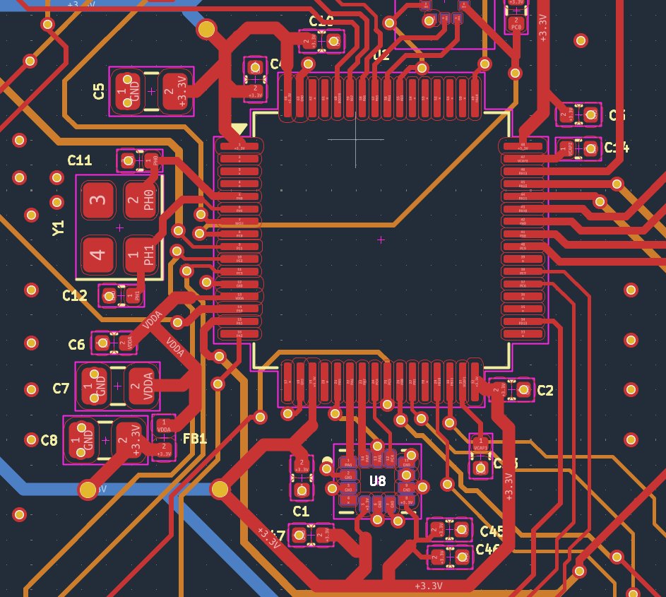
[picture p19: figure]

Figure 19: STM32F405 area — decoupling capacitors on all VDD pins, crystal C11/C12, VDDA filter

The STM32F405 LQFP-64 is placed in the upper-center of the board. Each of the four VDD pins has its own 100 nF decoupling capacitor placed as close as physically possible — within 1 mm of the pin, with the cap GND pad connected by a very short trace to a via down to the In1.Cu GND plane. The 4.7 µF bulk cap C5 is placed just outside the LQFP body.

The VCAP capacitors C13 and C14 (2.2 µF each) are placed at VCAP1 (pin 31) and VCAP2 (pin 47) with minimal trace length. These are on the left and right sides of the STM32 respectively, matching pin positions. Long VCAP traces add inductance that destabilizes the internal core voltage regulator.

The crystal Y1 is placed to the left of the STM32, directly adjacent to PH0 and PH1 pins. C11 and C12 load capacitors are placed within 2 mm of the crystal body, with their GND pins connected to a dedicated GND via rather than the general GND pour — this provides a clean, low-impedance return path that minimizes noise coupling into the crystal circuit. The crystal traces are kept short (<5 mm total) and routed away from any high-speed signals.

## 14.5 IMU Layout — U8

Figure 20: ICM-42688-P IMU area — QFN package, ground via stitching, decoupling caps C1/C45/C46

The ICM-42688-P is a 14-pin QFN package (3×2.5 mm) with a central thermal/GND pad. The thermal pad is connected to the In1.Cu GND plane via multiple thermal vias, providing both electrical ground connection and mechanical adhesion.

C45 (0.1 µF) and C46 (2.2 µF) placed on VDD pin (pin 8) within 1 mm
C1 (additional 100 nF) on adjacent VDD trace for distributed bypass
C47 (10 nF) on VDDIO pin (pin 5) — placed on opposite side of IC
All SPI traces (PA5/6/7, PC4) routed on F.Cu with ground pour directly above on In1.Cu
Ground vias placed adjacent to each SPI signal via to minimize ground return loop
The IMU should be placed as close to the center of the drone as possible to minimize the vibration arm that amplifies mechanical resonance. On this board it is placed near the geometric center, and soft-mount grommets are used at the mounting holes to further isolate vibration.

## 14.6 OSD & 5V Area Layout — U9, Y2

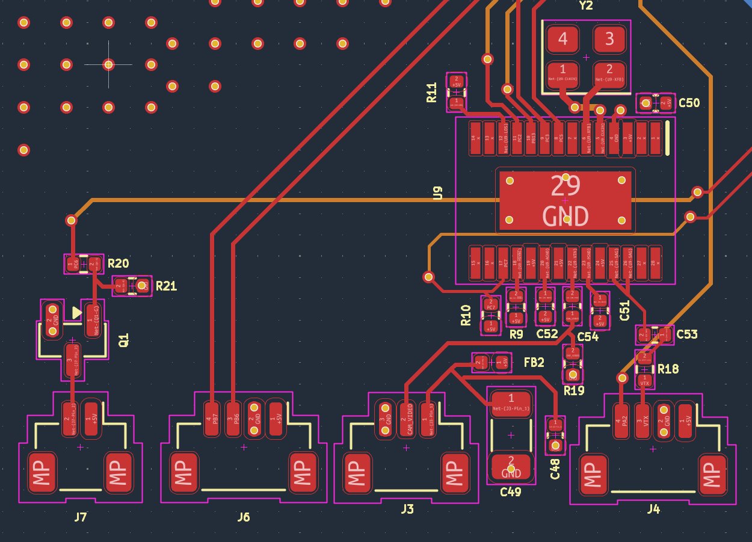
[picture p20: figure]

Figure 21: AT7456E OSD and 5V area — Y2 27MHz crystal, decoupling, video routing, R18/R19 termination

The AT7456E OSD chip (U9, 29-pin SOIC) occupies the lower-center of the board. The 27 MHz crystal Y2 is placed immediately adjacent to the CLKIN and XFB pins, with the shortest possible traces. Decoupling capacitors C50, C51, C52 are placed at each power pin of the IC.

R18 (75 Ω) and R19 (75 Ω) are the video termination resistors — placed close to connector
Video traces (CAM_VIDEO, VTX) are kept short and away from SPI/UART digital signals
The OSD thermal pad is connected to GND plane via vias
FB2 (600 Ω ferrite) and C49 (100 µF) filter camera 5V supply at J3 connector
Q1 buzzer MOSFET is placed next to J7 connector, with R20/R21 immediately at gate pin

## 14.7 Barometer Layout — U7

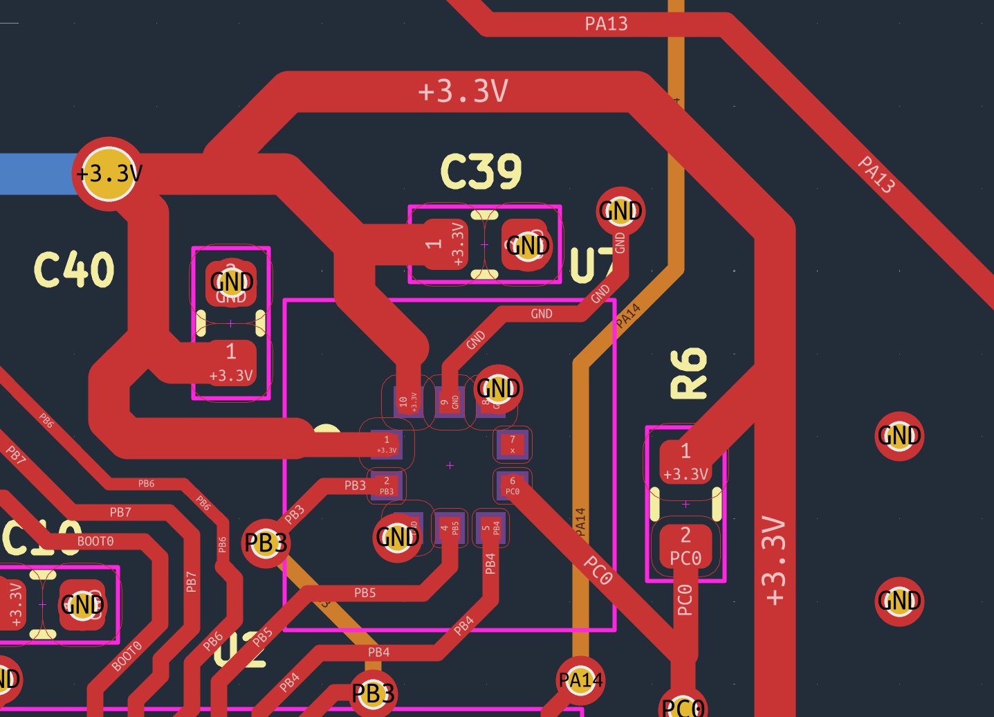
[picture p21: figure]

Figure 22: BMP388 barometer area — LCC package, VDDIO/VDD decoupling caps, SPI traces

The BMP388 is a small LCC package placed in the upper-right area of the board. C39 and C40 (100 nF each on VDD and VDDIO) are placed within 1 mm of their respective pins. The CS pull-up resistor R6 (4.7 kΩ) is placed adjacent to the CS pin. SPI3 traces (PB3/PB4/PB5) route from the STM32 to U7 on F.Cu.

The barometer measures absolute pressure to derive altitude. It should be placed away from heat-generating components (buck converter, power MOSFETs) because temperature gradients cause pressure measurement errors. It is also given vent holes in any enclosure to allow air pressure equalization.

## 14.8 Magnetometer Layout — U3

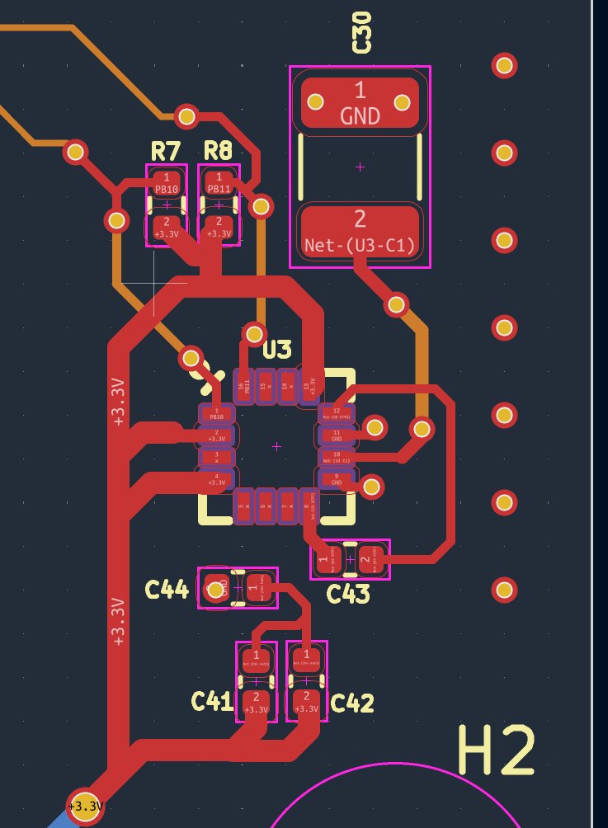
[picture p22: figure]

Figure 23: QMC5883L magnetometer layout — bottom-right corner, I2C pull-ups, SET/RESET cap C43

The QMC5883L (U3, LCC-16 package) is placed in the bottom-right corner of the board — the maximum distance from the power section and motor connectors on the opposite side. I2C pull-up resistors R7 and R8 (2.2 kΩ) are placed immediately adjacent to the SCL/SDA pins. C43 (0.22 µF SET/RESET cap) is placed between SETP and SETC pins with minimal trace length. C41, C42, C44 decoupling caps are placed within 2 mm of VDD pins.

Even with careful board placement, the magnetometer will experience interference from motor currents in flight. Betaflight's compass calibration routine and flight-time motor interference compensation algorithms are used in firmware to correct for this.

## 14.9 GPS Module Layout — U6

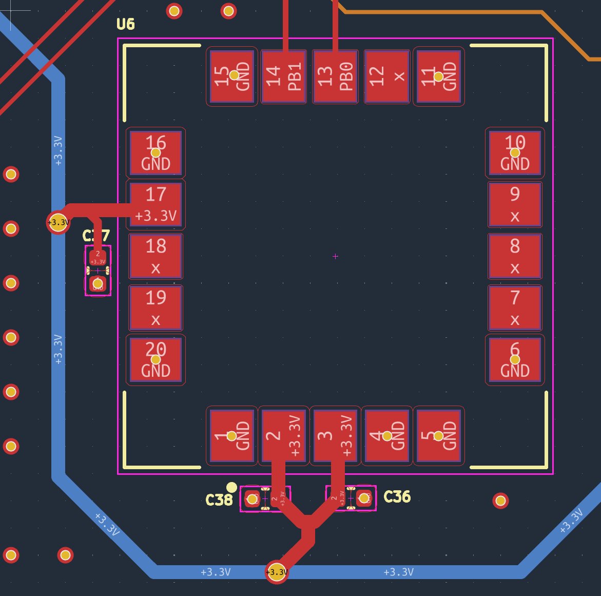
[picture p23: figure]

Figure 24: SAM-M10Q GPS module layout — LCC package, three decoupling rails, UART routing

The SAM-M10Q (U6) is a large LCC package (3×3 mm with exposed pads). Three sets of decoupling capacitors (C36, C37, C38 — 100 nF each) are placed immediately at the VCC, V_IO, and V_BCKP pins respectively. UART3 traces (PB0/PB1) route from the STM32 area to the GPS module pins. All GND pads of the module are connected to the In1.Cu GND plane via vias.

The GPS is placed with the antenna-side of the module (the die-integrated patch) facing upward with clear vertical sky view. No tall components are placed within the module's antenna footprint area. The blue traces visible in the layout image are the 3.3V B.Cu distribution layer showing through from the back copper.

## 14.10 USB-C Layout

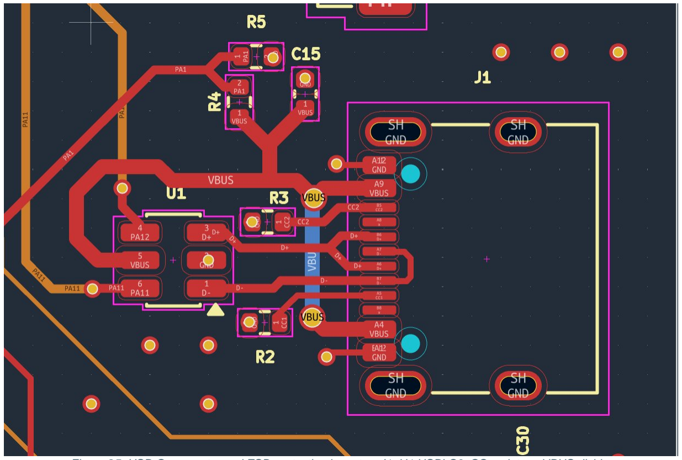
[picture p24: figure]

Figure 25: USB-C connector and ESD protection layout — J1, U1 USBLC6, CC resistors, VBUS divider

The USB-C connector (J1) is mounted at the right edge of the board for easy access. The USBLC6-2SC6 ESD protection IC (U1, SOT-23-6) is placed as close as possible to the connector — before any other routing of the D+ and D− lines. This ensures ESD events are clamped before they can travel along the PCB traces to the STM32.

D+ and D− traces routed as a matched pair on F.Cu to U1, then to STM32 PA11/PA12
CC1/CC2 pull-down resistors R2/R3 placed immediately at the connector CC pins
VBUS divider R4/R5 placed adjacent to the VBUS pin with C15 bypass
Shield and GND pins connected directly to GND pour with multiple vias
The blue differential pair visible in the PCB image shows the USB D+/D− traces routed together with consistent spacing. While full impedance-controlled 90 Ω differential routing is ideal for USB 2.0, at Full Speed (12 Mbps) the signal integrity requirements are relaxed enough that matched-length traces with consistent separation are sufficient.

## 14.11 Crystal & VDDA Area

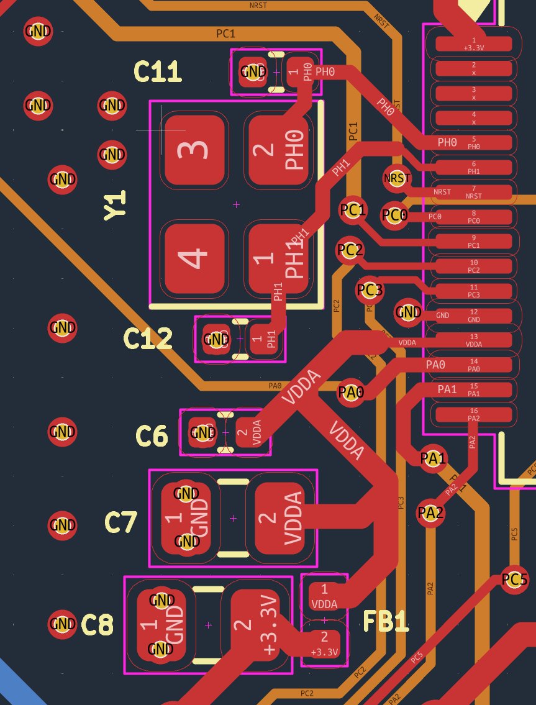
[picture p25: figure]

Figure 26: Crystal Y1 and VDDA filter area — C11/C12 load caps, FB1, C6/C7/C8 filter chain

The 8 MHz crystal Y1 is placed directly adjacent to STM32 pins PH0 and PH1 with load capacitors C11 and C12 flanking it. The traces from the crystal to the STM32 pins are kept under 5 mm total length. The crystal and its load caps are surrounded by a ground pour on F.Cu to shield the circuit from noise coupling.

The VDDA filter (FB1 ferrite bead, C6, C7, C8) is placed between the 3.3V B.Cu distribution layer and the VDDA pin of the STM32. C6 (10 nF) and C7 (1 µF) are on the input side of the ferrite bead, C8 (1 µF) is on the VDDA output side. The ferrite bead physically isolates the analog domain from the digital 3.3V rail noise.

## 14.12 Trace Widths & Impedance

Trace widths were assigned based on current capacity and signal type, using the IPC-2221 current capacity guidelines for 1 oz copper.

Net Class | Trace Width | Current / Use
VBAT Power | 1.5 mm | Up to 5A battery input — wide to minimize resistive drop
5V Power | 1.0 mm | Up to 3.5A buck output — wide power backbone
3.3V Power | 0.5 mm | ~500 mA digital rail — moderate width on B.Cu pour
GND Plane | Solid pour | Zero resistance — In1.Cu unbroken ground plane
SPI Signals | 0.2 mm | Low current digital — narrow for routing density
I2C Signals | 0.2 mm | Low current — standard signal trace
UART | 0.2 mm | Low current digital signal

USB D+/D− | 0.2 mm matched | Differential pair — matched length ±0.1 mm
Crystal | 0.15 mm | Minimal length, surrounded by GND pour
ADC inputs | 0.2 mm | Analog — kept away from switching signals

## 14.13 Ground Plane Strategy & Via Stitching

The In1.Cu ground plane is the most important layer in the stackup. It serves as the electromagnetic reference for every signal on the board, provides the return current path for all traces on F.Cu and In2.Cu, and acts as a thermal spreading layer.

In1.Cu is a solid, unbroken copper pour — no signal traces cut through it
Every component GND pad connects to In1.Cu via a short via within 1–2 mm
Via stitching around the board perimeter connects F.Cu GND pour to In1.Cu at regular intervals
Signal vias changing layers have a GND via placed <1 mm away — provides adjacent return path
The IMU, barometer, and crystal areas have dense GND via stitching to create solid local ground islands
When a signal via transitions from F.Cu to In2.Cu, its return current must also transition between reference planes. Without a nearby GND via, the return current travels a long path around the via, forming a loop that radiates EMI. The nearby GND via provides a direct, low-inductance return path that keeps the loop area minimal.

# 15. Manufacturing & BOM

The board was manufactured by JLCPCB as a 4-layer PCB with SMT assembly. The BOM was prepared with LCSC part numbers for all SMT components, enabling JLCPCB's Economic assembly service for the bulk of the components. The following components are hand-soldered after board delivery:

Category | Detail
PCB Manufacturer | JLCPCB
Board Size | 74 × 108 mm
Layers | 4 (F.Cu / In1.Cu / In2.Cu / B.Cu)
Material | FR4 TG135
Thickness | 1.6 mm
Copper Weight | 1 oz outer / 1 oz inner
Surface Finish | LeadFree HASL
Min Trace/Space | 0.15/0.15 mm
Min Via Drill | 0.3 mm
Quantity | 5 boards
SMT Assembly | JLCPCB Economic PCBA — top side
SMT Components | 43 line items, all LCSC-sourced
Hand-Solder Parts | J1–J10 connectors, SW1, SW2, L2, Q1, Y1, Y2
Estimated Cost (bare) | ~$44.92 for 5 boards
Assembly Cost | ~$272 total for 5 assembled boards

The BOM contains components from Samsung, Uniroyal, TI, ST, Bosch, TDK InvenSense, u-blox, MaxLinear, Diodes Inc., ZHONGKEWEI, and QST — all verified against official datasheets. Non-standard E96 series resistors (feedback and UVLO networks) were sourced from LCSC extended parts inventory.

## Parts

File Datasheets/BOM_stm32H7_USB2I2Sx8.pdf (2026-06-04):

Reference,Value,Datasheet,Footprint,Qty,DNP,Description
C1,C2,C3,C4,C5,C6,C7,C8,C9,C11,C15,C16,C17,C18,C25,C26,100n,-- valeurs mixtÃ©es --,Capacitor_SMD:C_0402_1005Metric,16,,-- valeurs mixtÃ©es --C10,100n/50V,https://jlcpcb.com/partdetail/Yageo-CC0603KRX7R9BB104/C14663,Capacitor_SMD:C_0603_1608Metric,1,,50V 100nF X7R Â±10% 0603 Multilayer Ceramic Capacitors MLCC - SMD/SMT - C14663 C12,C13,2.2u,https://jlcpcb.com/partdetail/24366-CL10A225KO8NNNC/C23630,-- valeurs mixtÃ©es --,2,,16V 2.2uF X5R Â±10% 0603 Multilayer Ceramic Capacitors MLCC C14,C19,33p,https://jlcpcb.com/partdetail/1914-0402CG330J500NT/C1562,Capacitor_SMD:C_0402_1005Metric,2,,50V 33pF C0G Â±5% 0402 Multilayer Ceramic Capacitors MLCC - SMD/SMT ROH C20,C21,C22,4.7uF,https://jlcpcb.com/partdetail/20375-CL10A475KO8NNNC/C19666,Capacitor_SMD:C_0603_1608Metric,3,,16V 4.7uF X5R Â±10% 0603 Multilayer Ceramic Capacitors MLCC - C19666 C23,C24,C27,C28,1uF,https://jlcpcb.com/partdetail/29074-CL21B105KBFNNNE/C28323,Capacitor_SMD:C_0805_2012Metric,4,,-- valeurs mixtÃ©es --F1,500mA,https://jlcpcb.com/partdetail/Littelfuse-0466500NRHF/C151133,Fuse:Fuse_1206_3216Metric,1,,50A SMD Fuse 500mA 63V 63V 1206 Fuses
H1,H2,H3,H4,MountingHole,~,MountingHole:MountingHole_3.2mm_M3,4,,
J1,USB_C_Receptacle_USB2.0_16P,https://www.usb.org/sites/default/files/documents/usb_type-c.zip,Connector_USB:USB_C_Receptacle_GCT_USB4110,1,,USB 2.0-only 16P Type-C Receptacle connector J2,Conn_02x14_Odd_Even,~,Connector_PinHeader_1.27mm:PinHeader_2x14_P1.27mm_Vertical,1,,"Generic connector, double row, 02x14, odd/even pin numbering scheme (row 1 odd numbers, row 2 even numbers), script generated (kicad-library-utils/schlib/autogen/connector/)" J4,Conn_01x04,~,Connector_PinHeader_1.27mm:PinHeader_1x04_P1.27mm_Vertical,1,,"Generic connector, single row, 01x04, script generated (kicad-library-utils/schlib/autogen/connector/)" JP1,SolderJumper_2_Open,~,Jumper:SolderJumper-2_P1.3mm_Open_TrianglePad1.0x1.5mm,1,,
R1,100k,~,Resistor_SMD:R_0603_1608Metric,1,,
R2,R3,1K5,https://jlcpcb.com/partdetail/26610-0402WGF1501TCE/C25867,Resistor_SMD:R_0402_1005Metric,2,,62.5mW Thick Film Resistors 50V Â±100ppm/â„ƒ Â±1% 1.5kÎ© 0402 Chip Resistor R4,0,https://jlcpcb.com/partdetail/21903-0603WAF0000T5E/C21189,Resistor_SMD:R_0201_0603Metric,1,,100mW Thick Film Resistors 75V Â±1% 0Î© 0603 Chip Resistor - Surface Mount ROHS R5,33,https://jlcpcb.com/partdetail/25848-0402WGF330JTCE/C25105,Resistor_SMD:R_0402_1005Metric,1,,62.5mW Thick Film Resistors 50V Â±100ppm/â„ƒ Â±1% 33Î© 0402 Chip Resistor R6,1M,~,Resistor_SMD:R_0603_1608Metric,1,,
R19,10k,~,Resistor_SMD:R_0603_1608Metric,1,,
R22,12k,~,Resistor_SMD:R_0603_1608Metric,1,,
SW1,SW2,SW_Push,~,Button_Switch_SMD:SW_Push_SPST_NO_Alps_SKRK,2,,
U1,STM32H723VGT6,STM32H723VGT6,Package_QFP:LQFP-100_14x14mm_P0.5mm,1,,
U2,USBLC6-2SC6,https://www.st.com/resource/en/datasheet/usblc6-2.pdf,Package_TO_SOT_SMD:SOT-23-6,1,,U3,USB3300-EZK,http://ww1.microchip.com/downloads/en/DeviceDoc/00001783C.pdf,Package_DFN_QFN:QFN-32-1EP_5x5mm_P0.5mm_EP3.45x3.45mm,1,,"Hi-Speed USB Host, Device or OTG PHY with ULPI Interface" U4,U7,TPS7A2033,https://www.ti.com/product/TPS7A20/part-details/TPS7A2033PDBVR,Package_TO_SOT_SMD:SOT-23-5,2,,300mA ultra-low-noise low-IQ low-dropout (LDO) linear regulator with high PSRR U5,NZ2520SDA-NSC5083D-45.1584MHz,https://www.ndk.com/en/products/lineup/crystal-oscillator/NZ2520SDA.html,Oscillator:Oscillator_SMD_Abracon_ASDMB-4Pin_2.5x2.0mm,1,,"SMD Ultra low phase noise suitable for high quality audio, NDK" U6,NZ2520SDA-NSC5083D-49.152MHz,https://www.ndk.com/en/products/lineup/crystal-oscillator/NZ2520SDA.html,Oscillator:Oscillator_SMD_Abracon_ASDMB-4Pin_2.5x2.0mm,1,,"SMD Ultra low phase noise suitable for high quality audio, NDK" Y1,8MHz,https://jlcpcb.com/partdetail/Yxc-X50328MSB2GI/C115962,Crystal:Crystal_SMD_5032-2Pin_5.0x3.2mm,1,,8MHz Surface mount crystal oscillator 20pF Â±10ppm Â±20ppm SMD5032 Crystals

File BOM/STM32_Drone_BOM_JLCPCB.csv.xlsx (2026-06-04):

Reference | Qty | Value | Footprint | LCSC Part #
C1,C2,C3,C4,C10,C15,C25,C36,C37,C38,C39,C40,C41,C42,C48,C55,C56 | 17 | 100n | Capacitor_SMD:C_0402_1005Metric | C1525
C5 | 1 | 4.7u | Capacitor_SMD:C_0805_2012Metric | C1779
C6,C34,C47 | 3 | 10n | Capacitor_SMD:C_0402_1005Metric | C15195
C7,C8 | 2 | 1u | Capacitor_SMD:C_0805_2012Metric | C28323
C9 | 1 | 100nF | Capacitor_SMD:C_0402_1005Metric | C1525
C11,C12 | 2 | 22p | Capacitor_SMD:C_0402_1005Metric | C1555
C13,C14,C35,C46 | 4 | 2.2u | Capacitor_SMD:C_0402_1005Metric | C12530
C23,C24,C30 | 3 | 4.7u | Capacitor_SMD:C_1210_3225Metric | C23733
C26 | 1 | 6800p | Capacitor_SMD:C_0402_1005Metric | C93654
C27,C29 | 2 | 47u | Capacitor_SMD:C_1210_3225Metric | C77101
C28 | 1 | 39p | Capacitor_SMD:C_0402_1005Metric | C106223
C33 | 1 | 1u | Capacitor_SMD:C_0402_1005Metric | C52923
C43 | 1 | 0.22u | Capacitor_SMD:C_0402_1005Metric | C16772
C44,C45,C50,C51,C52,C53,C54 | 7 | 0.1u | Capacitor_SMD:C_0402_1005Metric | C1525
C49 | 1 | 100u | Capacitor_SMD:C_1206_3216Metric | C15008
D2 | 1 | B560C-13-F | Custom:B560C-13F | C85100
FB1 | 1 | 120R | Inductor_SMD:L_0402_1005Metric | C38480
FB2 | 1 | 600R | Inductor_SMD:L_0402_1005Metric | C76884
R1 | 1 | 10K | Resistor_SMD:R_0402_1005Metric | C25744
R2,R3 | 2 | 5.1k | Resistor_SMD:R_0402_1005Metric | C25905
R4 | 1 | 33K | Resistor_SMD:R_0402_1005Metric | C25779
R5 | 1 | 82K | Resistor_SMD:R_0402_1005Metric | C1160
R6 | 1 | 4.7k | Resistor_SMD:R_0402_1005Metric | C25900
R7,R8 | 2 | 2.2k | Resistor_SMD:R_0402_1005Metric | C25879
R9,R10,R11 | 3 | 1k | Resistor_SMD:R_0402_1005Metric | C11702
R12 | 1 | 523k | Resistor_SMD:R_0402_1005Metric | C27011
R13 | 1 | 84.5k | Resistor_SMD:R_0402_1005Metric | C26988
R14 | 1 | 162k | Resistor_SMD:R_0402_1005Metric | C54068
R15 | 1 | 13k | Resistor_SMD:R_0402_1005Metric | C25754
R16 | 1 | 53.6k | Resistor_SMD:R_0402_1005Metric | C53398
R17 | 1 | 10.2k | Resistor_SMD:R_0402_1005Metric | C11660
R18,R19 | 2 | 75 | Resistor_SMD:R_0402_1005Metric | C25133
R20,R21,R22,R23,R25 | 5 | 10k | Resistor_SMD:R_0402_1005Metric | C25744
R24 | 1 | 100k | Resistor_SMD:R_0402_1005Metric | C25741
U1 | 1 | USBLC6-2SC6 | Package_TO_SOT_SMD:SOT-23-6 | C7519
U2 | 1 | STM32F405RGTx | Package_QFP:LQFP-64_10x10mm_P0.5mm | C15742
U3 | 1 | QMC5883L | Custom:LPCC-16 | C976032
U4 | 1 | SPX3819M5-L-3-3 | Package_TO_SOT_SMD:SOT-23-5 | C9055
U5 | 1 | TPS54360DDA | Package_SO:TI_SO-PowerPAD-8_ThermalVias | C465733
U6 | 1 | SAM-M10Q-00B | Custom:XCVR_SAM-M10Q-00B | C5443880
U7 | 1 | BMP388 | Custom:XDCR_BMP388 | C779278
U8 | 1 | ICM-42688-P | Custom:PQFN50P300X250X97-14N | C1850418
U9 | 1 | AT7456E | Custom:SOP65P640X120-29N | C82351

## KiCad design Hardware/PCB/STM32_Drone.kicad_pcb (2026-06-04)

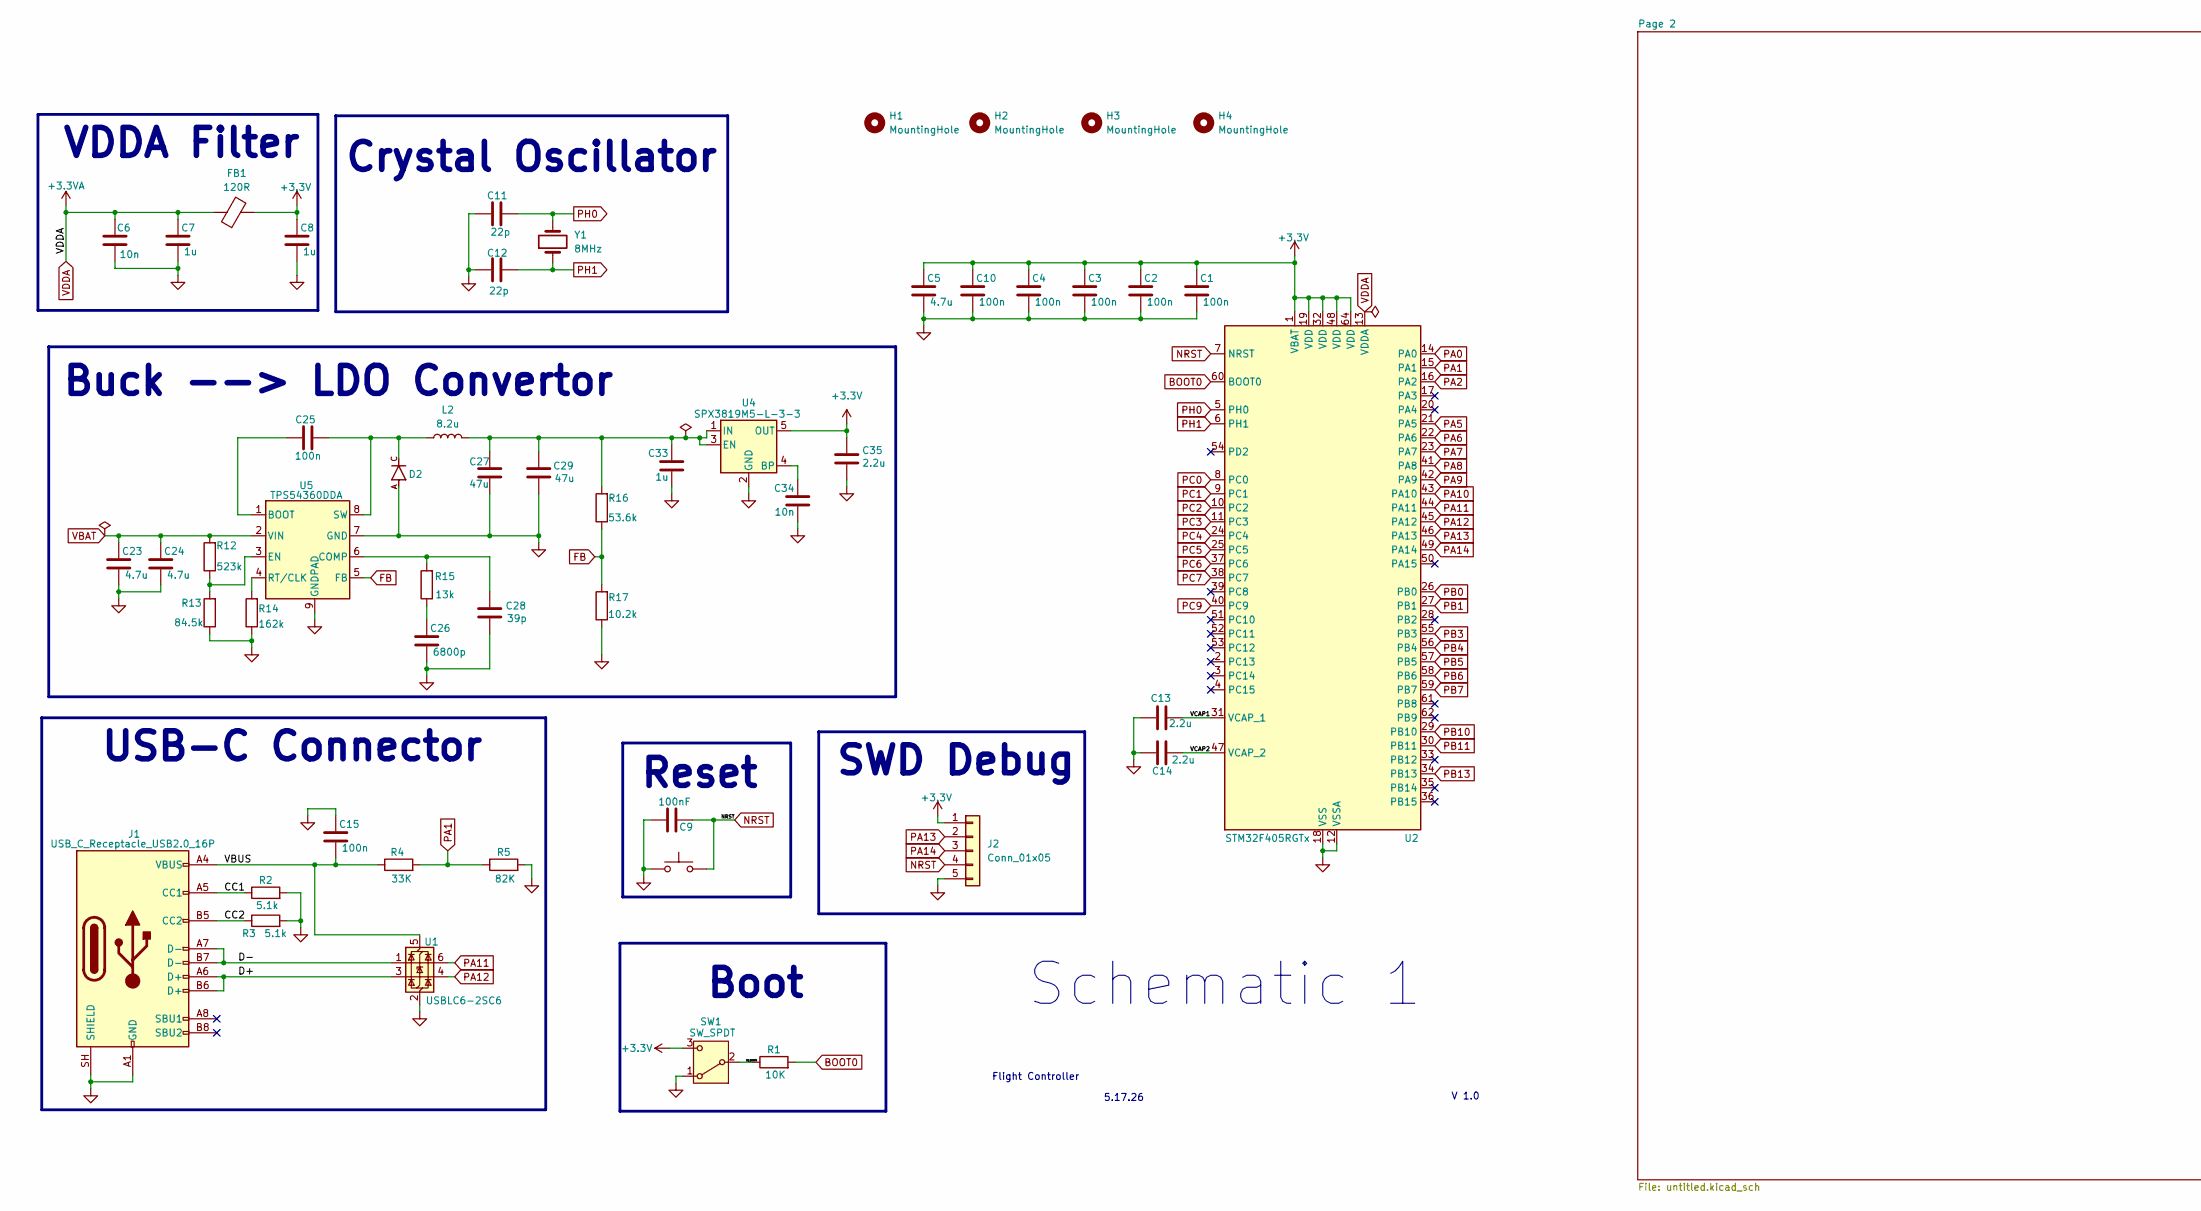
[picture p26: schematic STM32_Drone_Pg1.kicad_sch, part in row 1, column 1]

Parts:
C1, C2, C3, C4, C10, C15, C25: 100n; C_0402_1005Metric
C5: 4.7u; C_0805_2012Metric
C6, C34: 10n; C_0402_1005Metric
C7, C8: 1u; C_0805_2012Metric
C9: 100nF; C_0402_1005Metric
C11, C12: 22p; C_0402_1005Metric
C13, C14, C35: 2.2u; C_0402_1005Metric
C23, C24: 4.7u; C_1210_3225Metric
C26: 6800p; C_0402_1005Metric
C27, C29: 47u; C_1210_3225Metric
C28: 39p; C_0402_1005Metric
C33: 1u; C_0402_1005Metric
D2: B560C-13-F; B560C-13F
FB1: 120R; L_0402_1005Metric
H1, H2, H3, H4: MountingHole; MountingHole_3.2mm_M3
J1: USB_C_Receptacle_USB2.0_16P; USB_C_Receptacle_XKB_U262-16XN-4BVC11
J2: Conn_01x05; PinHeader_1x05_P2.54mm_Vertical
L2: 8.2u; L_7.3x7.3_H3.5
R1: 10K; R_0402_1005Metric
R2, R3: 5.1k; R_0402_1005Metric
R4: 33K; R_0402_1005Metric
R5: 82K; R_0402_1005Metric
R12: 523k; R_0402_1005Metric
R13: 84.5k; R_0402_1005Metric
R14: 162k; R_0402_1005Metric
R15: 13k; R_0402_1005Metric
R16: 53.6k; R_0402_1005Metric
R17: 10.2k; R_0402_1005Metric
SW1: SW_SPDT; SW_SPDT_CK_JS102011SAQN
SW2: SW_Push; SW_Push_1P1T_XKB_TS-1187A
U1: USBLC6-2SC6; SOT-23-6
U2: STM32F405RGTx; LQFP-64_10x10mm_P0.5mm
U4: SPX3819M5-L-3-3; SOT-23-5
U5: TPS54360DDA; TI_SO-PowerPAD-8_ThermalVias
Y1: 8MHz; Crystal_SMD_3225-4Pin_3.2x2.5mm

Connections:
+3.3V: C1.2, C2.2, C3.2, C4.2, C5.2, C8.2, C10.2, C35.1, FB1.2, J2.1, SW1.3 (C), U2.1 (VBAT), U2.19 (VDD), U2.32 (VDD), U2.48 (VDD), U2.64 (VDD), U4.5 (OUT); also elsewhere on the board
/CC1: J1.A5 (CC1), R2.1
/CC2: J1.B5 (CC2), R3.1
/D+: J1.A6 (D+), J1.B6 (D+), U1.3 (I/O2)
/D-: J1.A7 (D-), J1.B7 (D-), U1.1 (I/O1)
/SW_BOOT0: R1.1, SW1.2 (B)
/VBUS: C15.1, J1.A4 (VBUS), J1.A9 (VBUS), J1.B4 (VBUS), J1.B9 (VBUS), R4.1, U1.5 (VBUS)
/VCAP1: C13.1, U2.31 (VCAP_1)
/VCAP2: C14.1, U2.47 (VCAP_2)
BOOT0: R1.2, U2.60 (BOOT0)
FB: R16.1, R17.2, U5.5 (FB)
GND: C1.1, C2.1, C3.1, C4.1, C5.1, C6.1, C7.1, C8.1, C9.1, C10.1, C11.2, C12.2, C13.2, C14.2, C15.2, C23.1, C24.1, C26.1, C27.1, C28.1, C29.1, C33.2, C34.2, C35.2, D2.A, J1.A1 (GND), J1.A12 (GND), J1.B1 (GND), J1.B12 (GND), J1.SH (SHIELD), J2.5, R2.2, R3.2, R5.2, R13.1, R14.1, R17.1, SW1.1 (A), SW2.1, U1.2 (GND), U2.12 (VSSA), U2.18 (VSS), U2.63 (VSS), U4.2 (GND), U5.7 (GND), U5.9 (GNDPAD); also elsewhere on the board
NRST: C9.2, J2.4, SW2.2, U2.7 (NRST)
unnamed: C26.2, R15.1
unnamed: C34.1, U4.4 (BP)
unnamed: C27.2, C29.2, C33.1, L2.2, R16.2, U4.1 (IN), U4.3 (EN)
unnamed: C25.2, U5.1 (BOOT)
unnamed: C28.2, R15.2, U5.6 (COMP)
unnamed: R12.1, R13.2, U5.3 (EN)
unnamed: R14.2, U5.4 (RT/CLK)
unnamed: C25.1, D2.C, L2.1, U5.8 (SW)
PA0: U2.14 (PA0); also elsewhere on the board
PA1: R4.2, R5.1, U2.15 (PA1)
PA2: U2.16 (PA2); also elsewhere on the board
PA5: U2.21 (PA5); also elsewhere on the board
PA6: U2.22 (PA6); also elsewhere on the board
PA7: U2.23 (PA7); also elsewhere on the board
PA8: U2.41 (PA8); also elsewhere on the board
PA9: U2.42 (PA9); also elsewhere on the board
PA10: U2.43 (PA10); also elsewhere on the board
PA11: U1.6 (I/O1), U2.44 (PA11)
PA12: U1.4 (I/O2), U2.45 (PA12)
PA13: J2.2, U2.46 (PA13)
PA14: J2.3, U2.49 (PA14)
PB0: U2.26 (PB0); also elsewhere on the board
PB1: U2.27 (PB1); also elsewhere on the board
PB3: U2.55 (PB3); also elsewhere on the board
PB4: U2.56 (PB4); also elsewhere on the board
PB5: U2.57 (PB5); also elsewhere on the board
PB6: U2.58 (PB6); also elsewhere on the board
PB7: U2.59 (PB7); also elsewhere on the board
PB10: U2.29 (PB10); also elsewhere on the board
PB11: U2.30 (PB11); also elsewhere on the board
PB13: U2.34 (PB13); also elsewhere on the board
PC0: U2.8 (PC0); also elsewhere on the board
PC1: U2.9 (PC1); also elsewhere on the board
PC2: U2.10 (PC2); also elsewhere on the board
PC3: U2.11 (PC3); also elsewhere on the board
PC4: U2.24 (PC4); also elsewhere on the board
PC5: U2.25 (PC5); also elsewhere on the board
PC6: U2.37 (PC6); also elsewhere on the board
PC7: U2.38 (PC7); also elsewhere on the board
PC9: U2.40 (PC9); also elsewhere on the board
PH0: C11.1, U2.5 (PH0), Y1.2
PH1: C12.1, U2.6 (PH1), Y1.1
VBAT: C23.2, C24.2, R12.2, U5.2 (VIN); also elsewhere on the board
VDDA: C6.2, C7.2, FB1.1, U2.13 (VDDA)

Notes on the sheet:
V 1.0
SWD Debug
5.17.26
Boot
Reset
Schematic 1
Flight Controller
VDDA Filter
Buck --> LDO Convertor
Crystal Oscillator
USB-C Connector

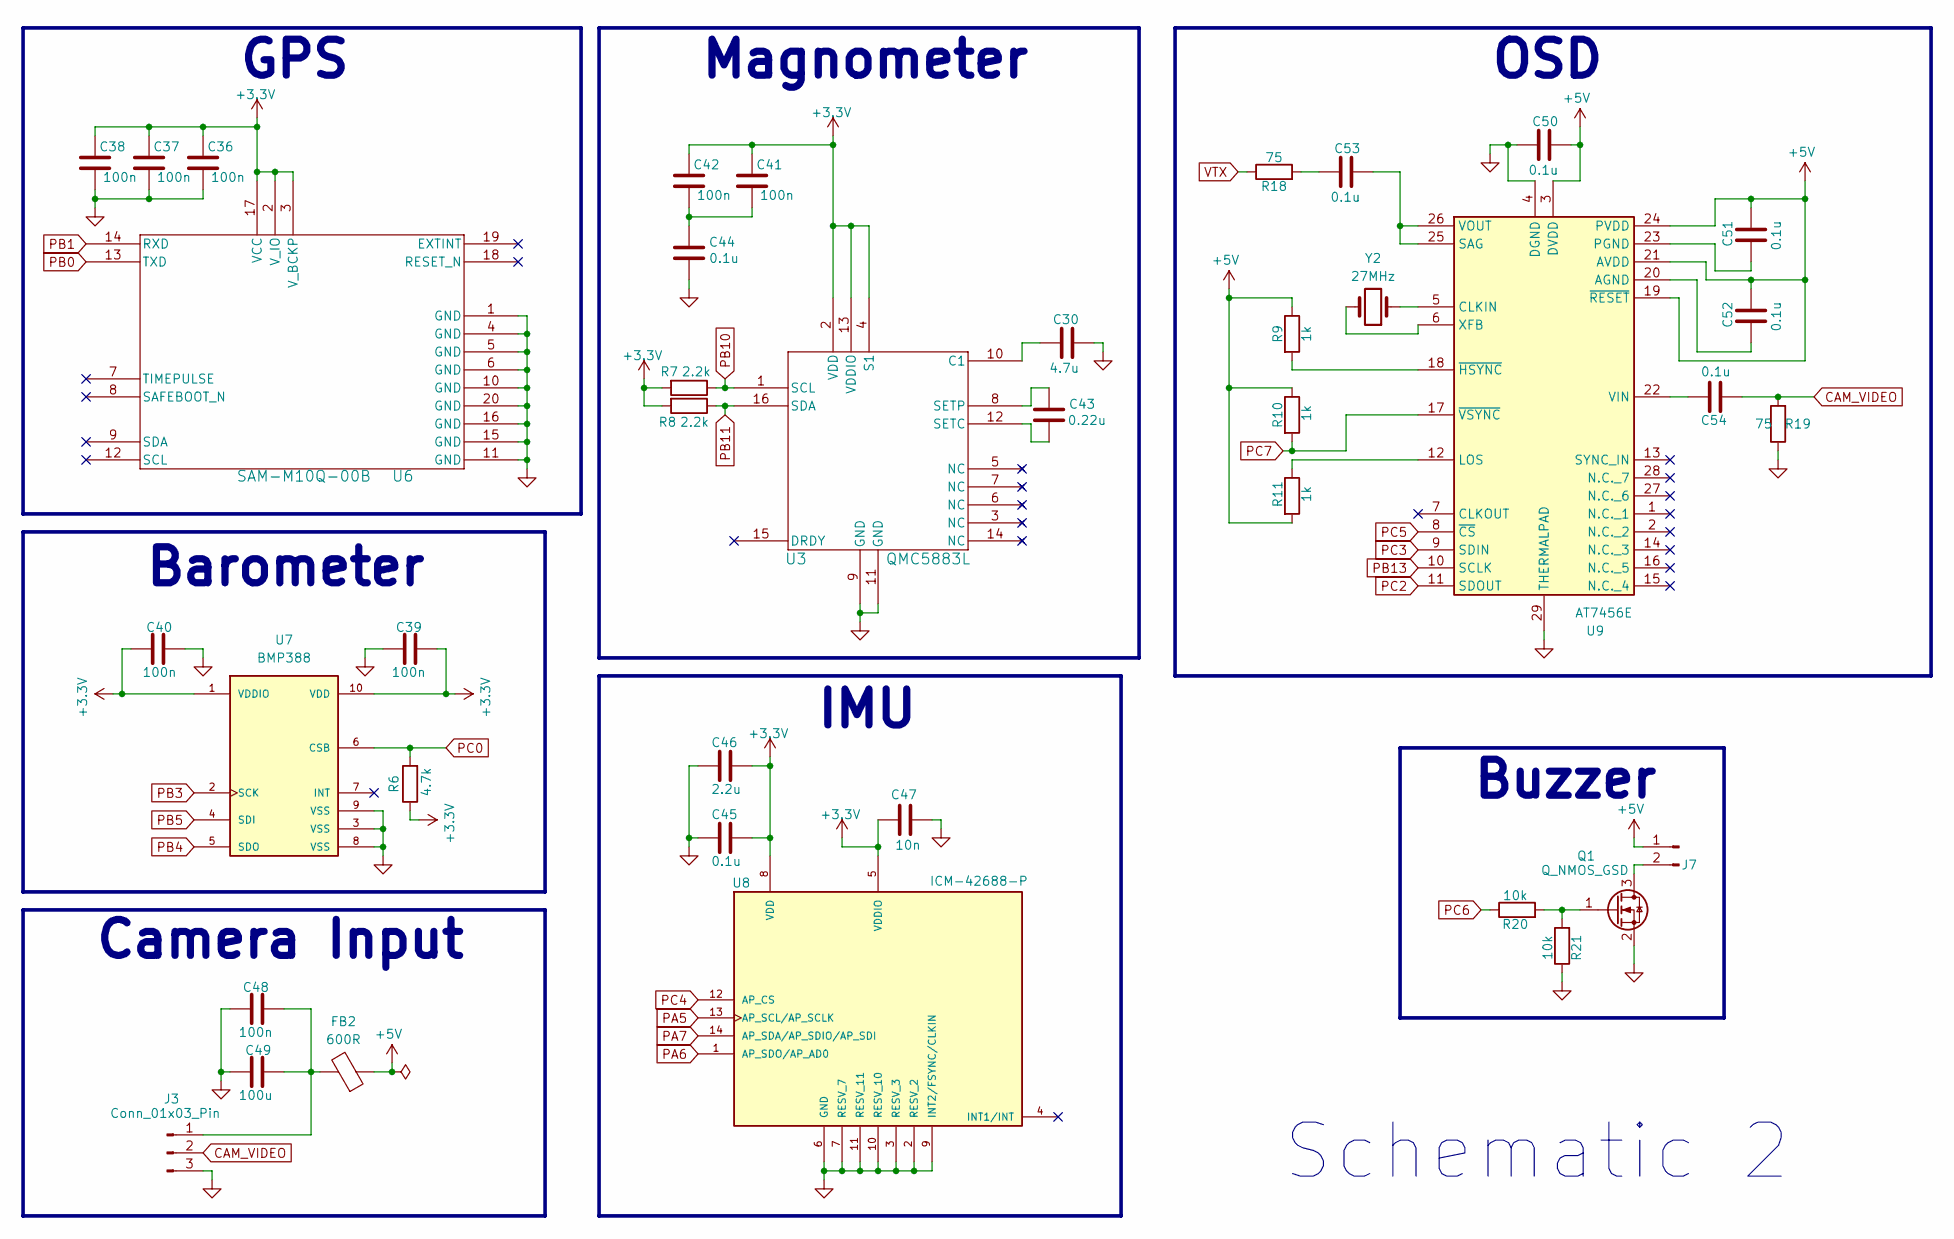
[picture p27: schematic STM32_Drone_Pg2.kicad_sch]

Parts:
C30: 4.7u; C_1210_3225Metric
C36, C37, C38, C39, C40, C41, C42, C48: 100n; C_0402_1005Metric
C43: 0.22u; C_0402_1005Metric
C44, C45, C50, C51, C52, C53, C54: 0.1u; C_0402_1005Metric
C46: 2.2u; C_0402_1005Metric
C47: 10n; C_0402_1005Metric
C49: 100u; C_1206_3216Metric
FB2: 600R; L_0402_1005Metric
J3: Conn_01x03_Pin; JST_SH_BM03B-SRSS-TB_1x03-1MP_P1.00mm_Vertical
J7: Conn_01x02_Pin; JST_SH_BM02B-SRSS-TB_1x02-1MP_P1.00mm_Vertical
Q1: Q_NMOS_GSD; SOT-23
R6: 4.7k; R_0402_1005Metric
R7, R8: 2.2k; R_0402_1005Metric
R9, R10, R11: 1k; R_0402_1005Metric
R18, R19: 75; R_0402_1005Metric
R20, R21: 10k; R_0402_1005Metric
U3: QMC5883L; LPCC-16
U6: SAM-M10Q-00B; XCVR_SAM-M10Q-00B
U7: BMP388; XDCR_BMP388; PARTREV 1.7
U8: ICM-42688-P; PQFN50P300X250X97-14N; PARTREV 1.2
U9: AT7456E; SOP65P640X120-29N; Manufacturer_Part_Number AT7456E
Y2: 27MHz; Crystal_SMD_3225-4Pin_3.2x2.5mm

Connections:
+3.3V: C36.2, C37.2, C38.2, C39.1, C40.1, C41.2, C42.2, C45.2, C46.2, C47.2, R6.1, R7.2, R8.2, U3.2 (VDD), U3.4 (S1), U3.13 (VDDIO), U6.2 (V_IO), U6.3 (V_BCKP), U6.17 (VCC), U7.1 (VDDIO), U7.10 (VDD), U8.5 (VDDIO), U8.8 (VDD); also elsewhere on the board
+5V: C50.2, C51.2, C52.2, FB2.1, J7.1, R9.1, R10.1, R11.2, U9.3 (DVDD), U9.19 (~RESET), U9.21 (AVDD), U9.24 (PVDD); also elsewhere on the board
CAM_VIDEO: C54.1, J3.2, R19.2
GND: C30.1, C36.1, C37.1, C38.1, C39.2, C40.2, C44.2, C45.1, C46.1, C47.1, C48.2, C49.2, C50.1, J3.3, Q1.2 (S), R19.1, R21.1, U3.9 (GND), U3.11 (GND), U6.1 (GND), U6.4 (GND), U6.5 (GND), U6.6 (GND), U6.10 (GND), U6.11 (GND), U6.15 (GND), U6.16 (GND), U6.20 (GND), U7.3 (VSS), U7.8 (VSS), U7.9 (VSS), U8.2 (RESV_2), U8.3 (RESV_3), U8.6 (GND), U8.7 (RESV_7), U8.9 (INT2/FSYNC/CLKIN), U8.10 (RESV_10), U8.11 (RESV_11), U9.4 (DGND), U9.29 (THERMALPAD); also elsewhere on the board
unnamed: C41.1, C42.1, C44.1
unnamed: C53.1, R18.2
unnamed: C48.1, C49.1, FB2.2, J3.1
unnamed: J7.2, Q1.3 (D)
unnamed: Q1.1 (G), R20.2, R21.2
unnamed: C30.2, U3.10 (C1)
unnamed: C43.2, U3.12 (SETC)
unnamed: C43.1, U3.8 (SETP)
unnamed: C52.1, U9.20 (AGND)
unnamed: U9.5 (CLKIN), Y2.1
unnamed: R11.1, U9.12 (LOS)
unnamed: C51.1, U9.23 (PGND)
unnamed: C53.2, U9.25 (SAG), U9.26 (VOUT)
unnamed: C54.2, U9.22 (VIN)
unnamed: U9.6 (XFB), Y2.2
unnamed: R9.2, U9.18 (~HSYNC)
PA5: U8.13 (AP_SCL/AP_SCLK); also elsewhere on the board
PA6: U8.1 (AP_SDO/AP_AD0); also elsewhere on the board
PA7: U8.14 (AP_SDA/AP_SDIO/AP_SDI); also elsewhere on the board
PB0: U6.13 (TXD); also elsewhere on the board
PB1: U6.14 (RXD); also elsewhere on the board
PB3: U7.2 (SCK); also elsewhere on the board
PB4: U7.5 (SDO); also elsewhere on the board
PB5: U7.4 (SDI); also elsewhere on the board
PB10: R7.1, U3.1 (SCL); also elsewhere on the board
PB11: R8.1, U3.16 (SDA); also elsewhere on the board
PB13: U9.10 (SCLK); also elsewhere on the board
PC0: R6.2, U7.6 (CSB); also elsewhere on the board
PC2: U9.11 (SDOUT); also elsewhere on the board
PC3: U9.9 (SDIN); also elsewhere on the board
PC4: U8.12 (AP_CS); also elsewhere on the board
PC5: U9.8 (~CS); also elsewhere on the board
PC6: R20.1; also elsewhere on the board
PC7: R10.2, U9.17 (~VSYNC); also elsewhere on the board
VTX: R18.1; also elsewhere on the board

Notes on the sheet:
OSD
Barometer
Schematic 2
Buzzer
Magnometer
IMU
GPS
Camera Input

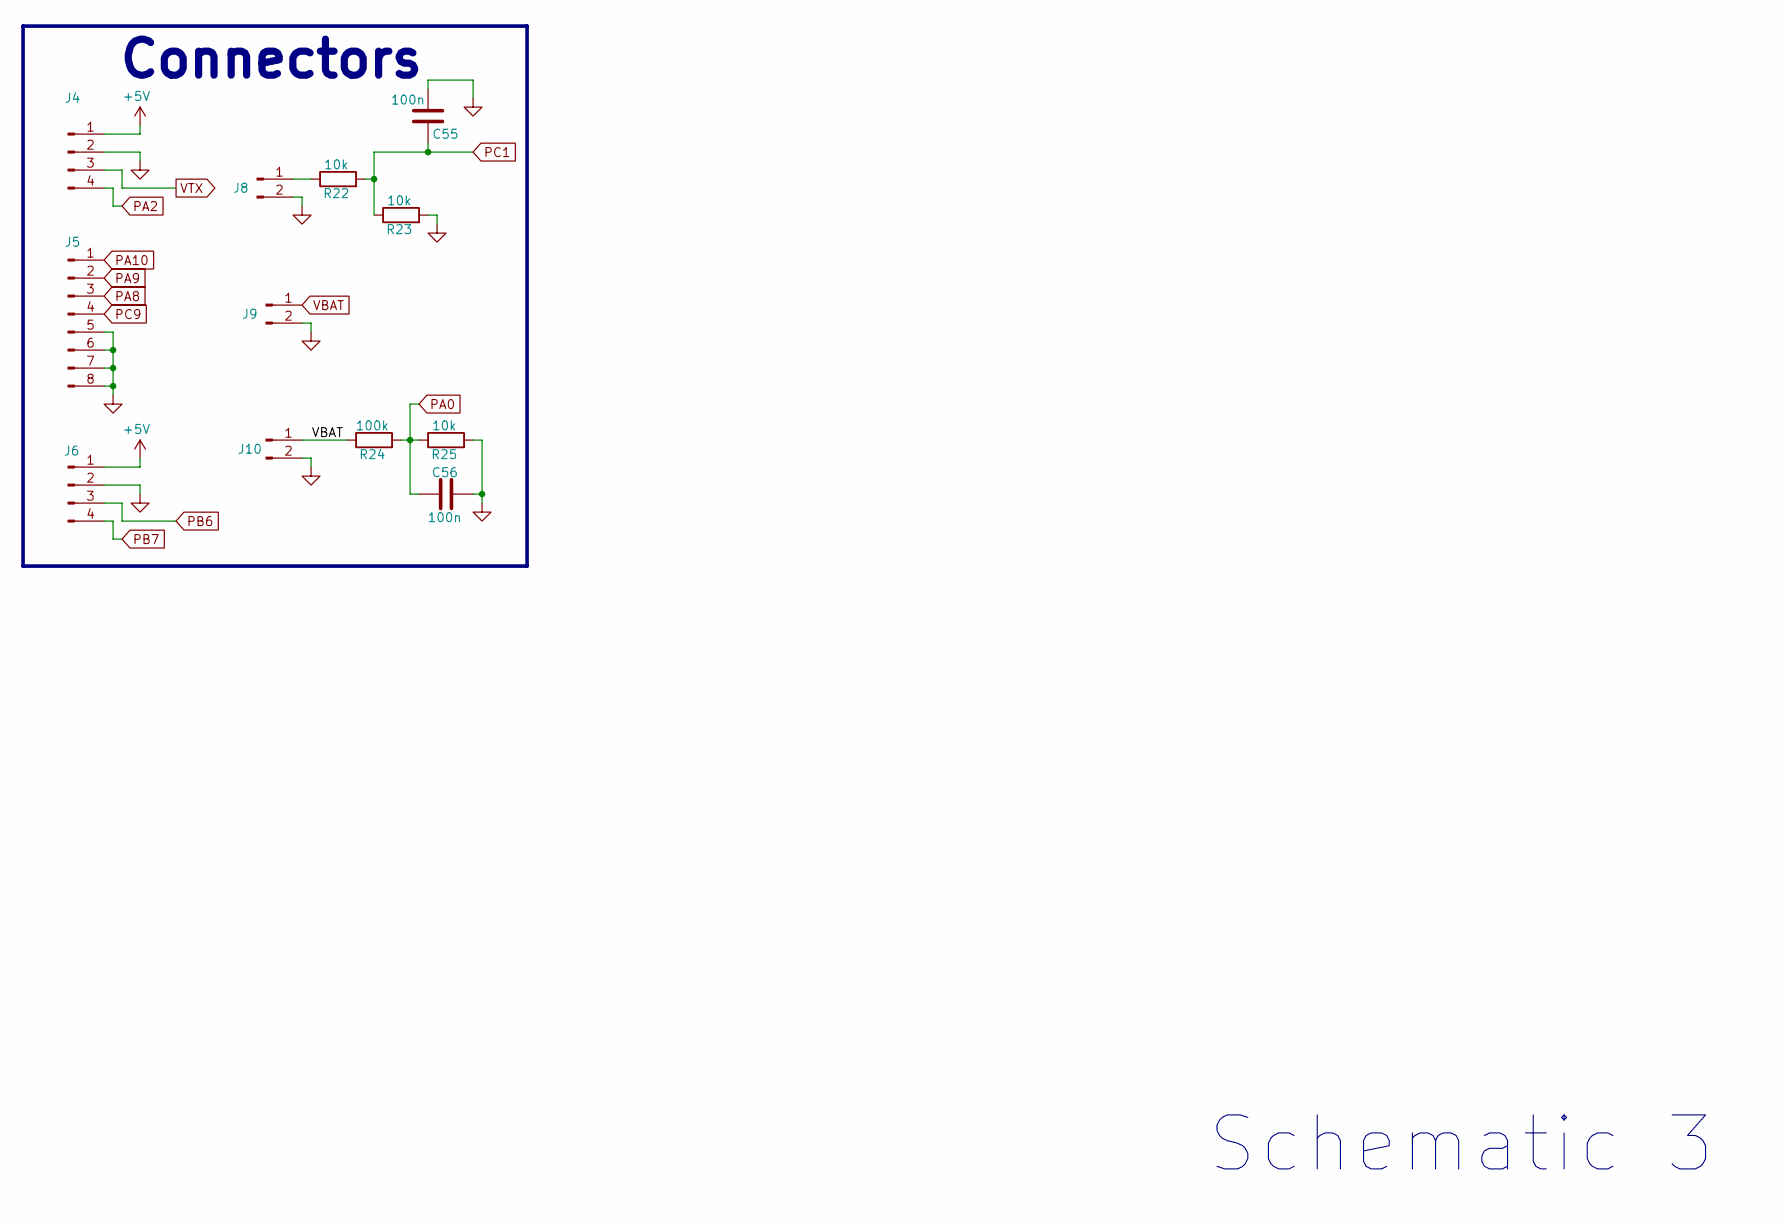
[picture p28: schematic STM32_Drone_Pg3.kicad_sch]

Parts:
C55, C56: 100n; C_0402_1005Metric
J4, J6: Conn_01x04_Pin; JST_SH_BM04B-SRSS-TB_1x04-1MP_P1.00mm_Vertical
J5: Conn_01x08_Pin; JST_SH_BM08B-SRSS-TB_1x08-1MP_P1.00mm_Vertical
J8: Conn_01x02_Pin; JST_SH_BM02B-SRSS-TB_1x02-1MP_P1.00mm_Vertical
J9, J10: Conn_01x02_Pin; AMASS_XT30PW-F_1x02_P2.50mm_Horizontal
R22, R23, R25: 10k; R_0402_1005Metric
R24: 100k; R_0402_1005Metric

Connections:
+5V: J4.1, J6.1; also elsewhere on the board
GND: C55.2, C56.1, J4.2, J5.5, J5.6, J5.7, J5.8, J6.2, J8.2, J9.2, J10.2, R23.2, R25.2; also elsewhere on the board
unnamed: J8.1, R22.1
PA0: C56.2, R24.2, R25.1; also elsewhere on the board
PA2: J4.4; also elsewhere on the board
PA8: J5.3; also elsewhere on the board
PA9: J5.2; also elsewhere on the board
PA10: J5.1; also elsewhere on the board
PB6: J6.3; also elsewhere on the board
PB7: J6.4; also elsewhere on the board
PC1: C55.1, R22.2, R23.1; also elsewhere on the board
PC9: J5.4; also elsewhere on the board
VBAT: J9.1, J10.1, R24.1; also elsewhere on the board
VTX: J4.3; also elsewhere on the board

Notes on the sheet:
Connectors
Schematic 3

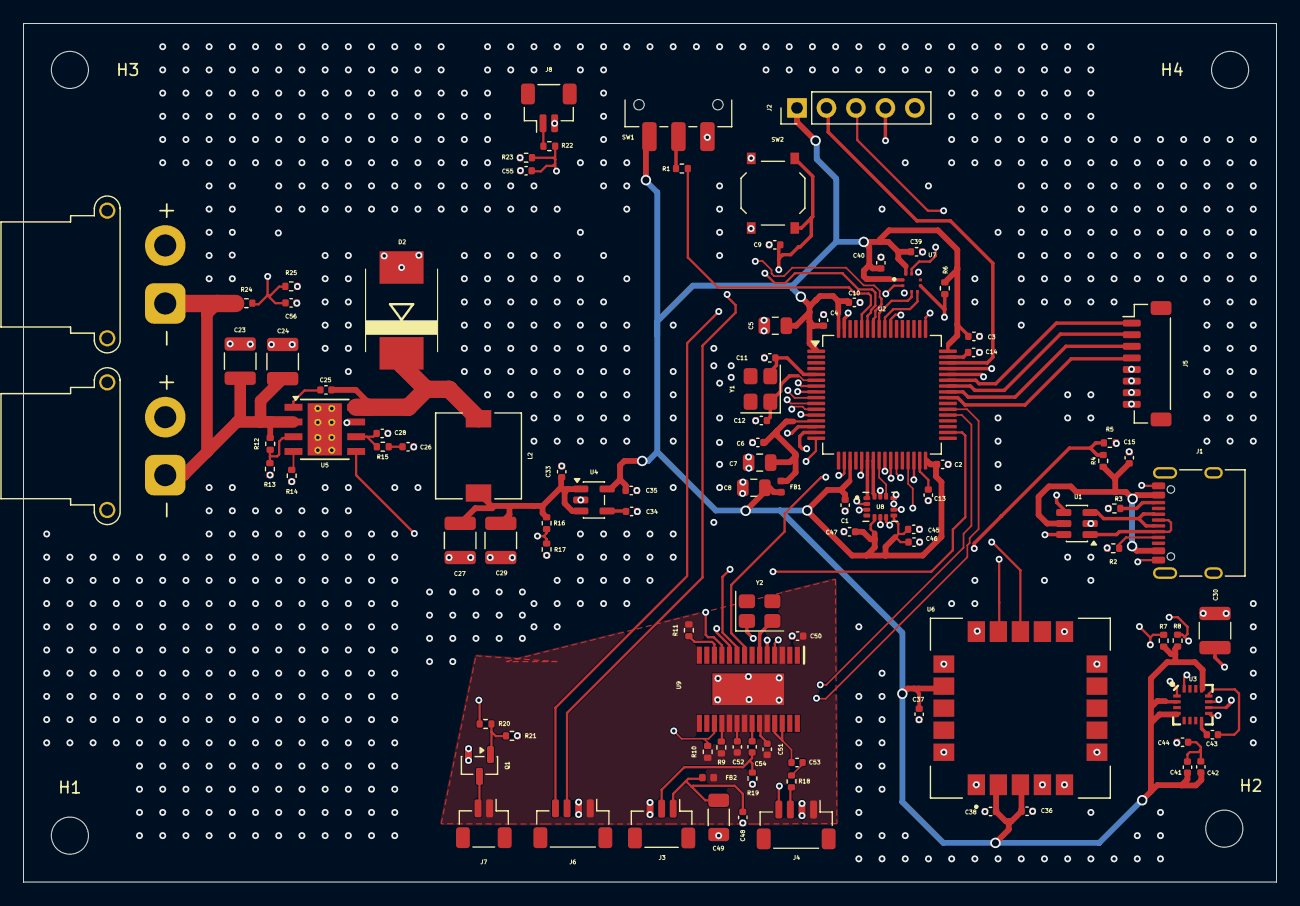
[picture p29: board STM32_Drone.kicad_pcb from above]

Board: 4 copper layers, 108.0 x 74.0 mm, 104 parts (0 on the bottom side), 77 nets.

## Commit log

2026-06-04 Revise README
    Updated README to enhance clarity and detail about the STM32F405 quadcopter flight controller, including specifications, repository structure, design portfolio, and key design decisions.
2026-06-04 BOM files added
    [STM32_Drone_BOM_JLCPCB.csv.xlsx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]
2026-06-04 Added hardware folder
    [STM32_Drone-B_Cu.gbl, STM32_Drone-B_Mask.gbs, STM32_Drone-B_Silkscreen.gbo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]
